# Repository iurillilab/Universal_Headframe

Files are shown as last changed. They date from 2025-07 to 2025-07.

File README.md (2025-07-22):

IIT-Rovereto Modular Mouse Headframe Clamp  
===========================================  

> A lightweight, Allen-compatible head-fixation system for imaging, electrophysiology and FUS studies  
> *Design series NT_NCS002* – by **Fabio Ricci** & **Giuliano Iurilli**, IIT Center for Neuroscience and Cognitive Systems, Rovereto (Italy), 2024 – 25

---
323248352-13070441-1c27-4a35-8a60-9cb97c2f6576

## 1. Purpose  

Sharing mice and rigs across projects is much simpler when the mechanical interface is identical everywhere.  
This repository provides the CAD, manufacturing drawings and assembly notes for the headframe clamp we use in the Gozzi, Iurilli and Rossi labs. The clamp:

* registers a titanium headplate (≈ 1.4 g) with micron-level repeatability;  
* mates directly to standard Thorlabs metric pillars or to a stereotaxic frame;  
* keeps the visual field unobstructed (design lineage: Allen Brain Observatory headframe);  
* survives running-mouse loads – static and dynamic deflection were bench-tested as ([P.A. Groblewski et al](https://www.sciencedirect.com/science/article/pii/S0165027020303459));  
* offers a kinematic reference that lets us reuse Allen Institute probe-positioning jigs and transparent hemisphere coordinate frames.

---

## 2. Repository layout  

```
/
├─ cad/               STEP
├─ drawings/          Dimensioned PDFs (NT_NCS002_001_P_001-004)
├─ bom/               CSV bill-of-materials
├─ headplate_variants/ Headplates STEP files
├─ accessories/       Accessories STEP files
└─ images/            Renders
```

---

## 3. Bill of Materials (BoM)  

| Item | Part No. | Qty | Material | Note |
|---|---|-----|---|---|
| 1 | **Stereotaxic mount** NT_NCS002_001_P_001 | 1 | SS 304 | Mates to KOPF/ASI frames |
| 2 | **Top headplate clamp** NT_NCS002_001_P_002 | 1 | SS 304 | Quick-release half-bridge |
| 3 | **Bottom headplate clamp** NT_NCS002_001_P_003 | 1 | SS 304 | Matches Allen bevel | 
| 4 | **Thorlabs pillar adapter** NT_NCS002_001_P_004 | 1 | SS 304 | Ø6 mm → Ø12.5 mm | 
| 5 | ISO 4026 M3×5 grub-screw | 2 | - | locking pins |
| 6 | ISO 4026 M3×8 grub-screw | 1 | - | axial stop |
| 7 | ISO 4762 M3 cap-screws (various 5–20 mm) | 6 | - | assembly |  

---

## 4. Fabrication guidelines  

* **CNC milling**: 3-axis is sufficient; minimum cutter Ø 1.6 mm.  
* **Tolerance**: unless stated,Dimensional Tolerance class -H Geometric Tolerance class -f, General tolerancesUNI EN 22768-1 / 22768-2 UNI ISO 8015
* **Surface finish**: Ra ≤ 1.6 µm on all mating faces; tumble-debur & passivate.  
* **Headplate**: Ti-TC4, 1.6 mm thick. The models in `/headplate_variants/` may be water-jet cut and bent or 3D printed by external manufacturer.  

---

## 5. Assembly & alignment workflow  

1. **Pre-load the clamp** – insert the M3 grub screws from the rear until flush.  
2. **Square to bregma** – fix the stereotaxic mount on the arm; use the printed bregma pointer to zero X/Y/Z.  
3. **Attach headplate to mouse** – follow your usual surgical SOP.  
4. **Clamp in** – slide the headplate under the bevel, tighten the single cap screw.  

---

## 6. Compatibility matrix  

| Instrument | Status | Notes |
|---|---|---|
| Wide-field mesoscope | ✅ | 200 mm working distance clears clamp |
| 2-photon 10× (Nikon A1R MP) | ✅ | headplate cone variant NT_NCS002_HP-C |
| Neuropixels v1.0/v2.0 | ✅ | uses Allen transparent coordinate frame |
| Functional -Ultrasound (FUS) | 🔄 | compatible cone in prototype (M. Urosevic) |

---

## 7. License  

All hardware documentation is released under **CERN-OHL-P v2**.  
You may manufacture and modify freely; derivatives must retain the same license and attribution.

---

## 8. Acknowledgements  

* Allen Institute open-hardware programme – for the original dual-hemisphere clamp design and coordinate frame  ([Toolkit - brain-map.org](https://portal.brain-map.org/explore/toolkit/hardware?utm_source=chatgpt.com)).  
* Iurilli laboratories for beta-testing across imaging and electrophysiology

---

*Maintainer*: **Fabio Ricci** – `<fabio.ricci@iit.it>`

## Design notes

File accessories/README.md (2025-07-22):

# Universal\_Headframe ─ Accessories Library 
Welcome!  This repository collects every **Accessories** we currently use or test at IIT Rovereto.  Each model comes as a STEP file (`.step`) ready for CAM / 3‑axis milling, direct metal‑AM printing, or SLA 3D printin, plus a PNG preview so you can eyeball the geometry before downloading CAD.

> **TL;DR**  • All files are **metric** (ISO M‑series screws, millimetres).

---

## How this README is organised

| Section | What you’ll find |
| --- | --- |
| [Quick chooser](#quick-chooser-table) | one‑line guide to pick the right plate |
| [Fabrication notes](#fabrication-notes) | tips for CNC vs SLM printing |

---

## Quick chooser table

| File name | Preview | Mass\* | Aperture Ø | Typical use‑case |
| --- | --- | --- | --- | --- |
| `0160-073-01_FR.step` || xx g | x mm | **Allen institute lineage** 	Cone for 2P|
| `Stamp_tool_SH_FR.step`|| xx  g | x mm | **Allen institute lineage** 	[SHIELD]( https://cad.onshape.com/publications/a9da3d5bea6057b1de9dcbe4/w/e8fb183696b8dd84a43603fb/e/8e9294519ca4564a8390c596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 ) stamp tool for creating impression of implant (0251-160-01) in putty during coating process|
| `DHC Stamp Tool_Stamp_tool_DH_FR.step`|| xx g | x mm |**Allen institute lineage**	[SHIELD]( https://cad.onshape.com/publications/a9da3d5bea6057b1de9dcbe4/w/e8fb183696b8dd84a43603fb/e/8e9294519ca4564a8390c596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 ) Dual Hemisphere Implant stamp tool for creating impression of implant (0274-100-22) in putty during coating process |
| `AH_USSEnterprise_cone_FR.step`|| xx g | x mm | **Skull‑contoured** cone for WFI compatible with AH_USSEnterprise_FR Headplate |
| `AH_USSEnterprise_cover.step`|| xx g | x mm |**Skull‑contoured** screwable open cover for the cone 			 |
| `Luigi_cone.step`|| xx g | x mm |Luigi Headplate variant cone for Ephys|
<sub>\*Mass values are printed Ti‑TC4 as measured on a 0.1 mg balance</sub>

---

## Fabrication notes

* **3‑D printing (SLM)** – upload to JLC3DP or similar; choose **Ti‑TC4** and "high precision" option if offered.
* **CNC milling** – water‑jet or laser‑cut 1.6 mm Ti sheet, then finish on 3‑axis mill;
* **3-D printing  (SLA)** - Used a Form 2 for parts that does not endure loads.

---

### Contributing

Pull requests welcome—open an issue if you have a new variant or measurement data to share.

### License

CERN-OHL-P-2.0 license.

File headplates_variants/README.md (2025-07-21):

# Universal\_Headframe ─ Variant Library 
Welcome!  This repository collects every **head‑plate variant** we currently use or test at IIT Rovereto.  Each model comes as a STEP file (`.step`) ready for CAM / 3‑axis milling, direct metal‑AM printing, or SLA 3D printin, plus a PNG preview so you can eyeball the geometry before downloading CAD.

> **TL;DR**  • All files are **metric** (ISO M‑series screws, millimetres). • Default material is **Ti‑TC4** (works in SLM or CNC), some of them can be made in plastic.

---

## How this README is organised

| Section | What you’ll find |
| --- | --- |
| [Quick chooser](#quick-chooser-table) | one‑line guide to pick the right plate |
| [Fabrication notes](#fabrication-notes) | tips for CNC vs SLM printing |

---

## Quick chooser table

| File name | Preview | Mass\* | Aperture Ø | Typical use‑case |
| --- | --- | --- | --- | --- |
| `0160-075-00_FR.step` | | xx g | x mm | **Allen institute lineage** 	titanium headframe utilized with the [SHIELD]( https://cad.onshape.com/publications/a9da3d5bea6057b1de9dcbe4/w/e8fb183696b8dd84a43603fb/e/8e9294519ca4564a8390c596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 ) implant for dual hemisphere electrophysiological recordings|
| `0251-900-04_FR.step` || xx  g | x mm | **Allen institute lineage**  Headframe-shank mounted stylus for setting stereotax clamp location with respect to Bregma|
| `0251-910-00_FR.step` || xx g | x mm |**Allen institute lineage**Headframe-shank mounted Whole Hemisphere Implant Tracer |
| `AH_USSEnterprise_FR.step` || xx g | x mm | **Skull‑contoured** geometry—full compatibility, acute imaging, [SHIELD]( https://cad.onshape.com/publications/a9da3d5bea6057b1de9dcbe4/w/e8fb183696b8dd84a43603fb/e/8e9294519ca4564a8390c596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 ) implant for dual hemisphere electrophysiological recordings |
| `DHC Tracer_FR.step` || xx g | x mm | Headframe-shank mounted Dual Hemisphere Implant Tracer 			 |
| `Eppendorf_FR.step` || xx g | x mm | Plate with keyed seat for Eppendorf to insert NP2 shanks |
| `Luigi_Headplate_V1_FR.step` || xx g | x mm | Luigi petrucco variant Ephys|
| `0160-055-00_X01_FR.step` || xx g | x mm | variant. |
| `0160-073-00_A_FR.step` || xx g | x mm | **Allen institute lineage** 	titanium headframe utilized with the [SHIELD]( https://cad.onshape.com/publications/a9da3d5bea6057b1de9dcbe4/w/e8fb183696b8dd84a43603fb/e/8e9294519ca4564a8390c596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 ) implant for whole hemisphere electrophysiological recordings - Version 2 - Ring style.|

<sub>\*Mass values are printed Ti‑TC4 as measured on a 0.1 mg balance</sub>

---

## Fabrication notes

* **3‑D printing (SLM)** – upload to JLC3DP or similar; choose **Ti‑TC4** and "high precision" option if offered.
* **CNC milling** – water‑jet or laser‑cut 1.6 mm Ti sheet, then finish on 3‑axis mill;
* **3-D printing  (SLA)** - Used a Form 2 for parts that does not endure loads.

---

### Contributing

Pull requests welcome—open an issue if you have a new variant or measurement data to share.

### License

CERN-OHL-P-2.0 license.

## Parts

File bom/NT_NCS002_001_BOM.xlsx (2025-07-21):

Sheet: components request
# | Cod. | Rev. | Q.ty | Mfg. Technology | Material | Notes | Optional column 1 | Optional column 2
1 | NT_BMP005_001_P_001 |  | 4 | CNC / Machine Tools
2 | NT_BMP005_001_P_002 |  | 4 | CNC / Machine Tools
3 | NT_BMP005_001_P_003 |  | 4 | CNC / Machine Tools
4 | NT_BMP005_003_P_004 |  | 4 | CNC / Machine Tools

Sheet: processes
Mgf. Technologies
Additive Mfg. (any)
SLS (ProX6100)
Polyjet (Connex500)
SLA (XFAB3500SD)
FFF (Fortus400)
CNC / Machine Tools
Waterjet
Inserts/Helicoils
Mech. Assembly
Reworked Comp.
Other

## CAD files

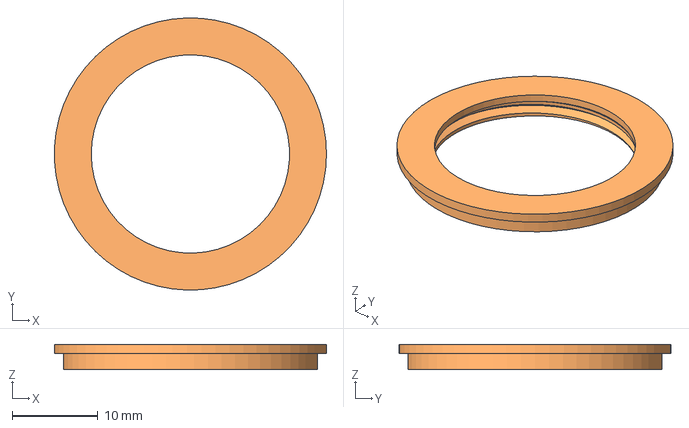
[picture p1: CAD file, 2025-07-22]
accessories/AH_USSEnterprise_cover.step
31.7 x 31.7 x 2.94 mm

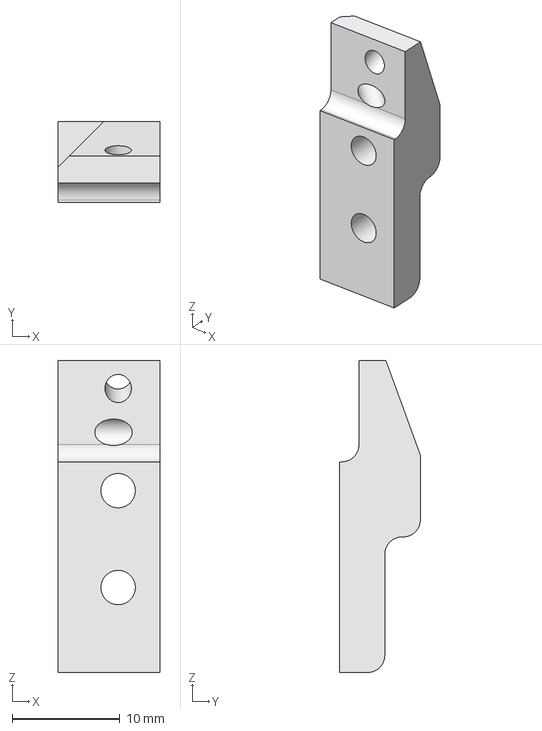
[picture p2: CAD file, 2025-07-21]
cad/NT_NCS002_001_P_002.stp
9.50 x 7.50 x 29.0 mm

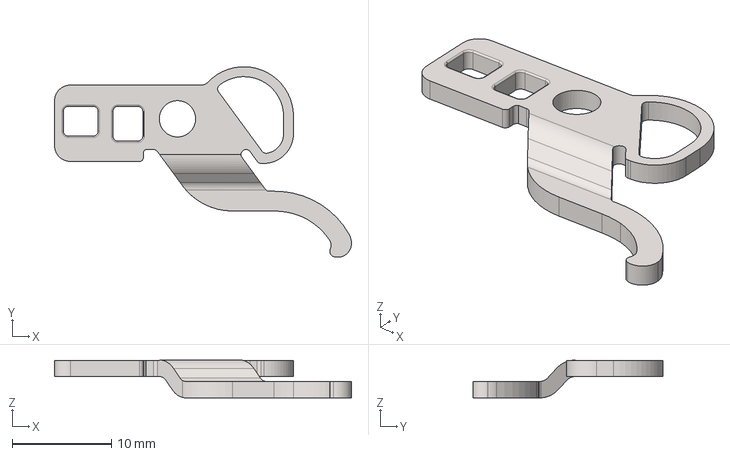
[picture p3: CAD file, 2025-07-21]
headplates_variants/Luigi_Headplate_V1_FR.step
29.9 x 19.2 x 3.83 mm

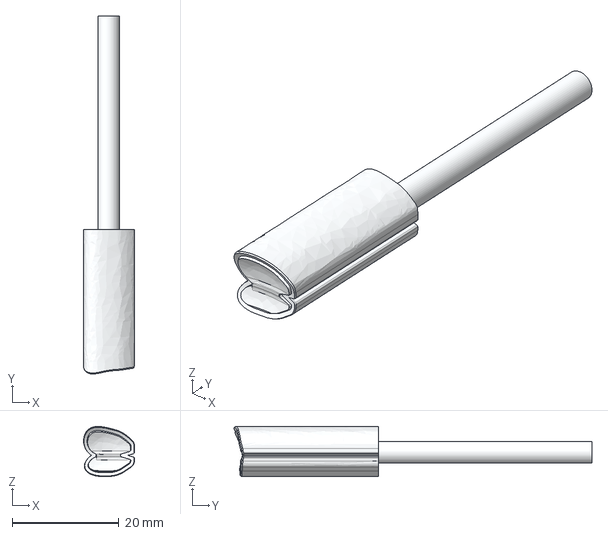
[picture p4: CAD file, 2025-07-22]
accessories/DHC Stamp Tool_Stamp_tool_DH_FR v1.step
9.54 x 67.1 x 9.39 mm

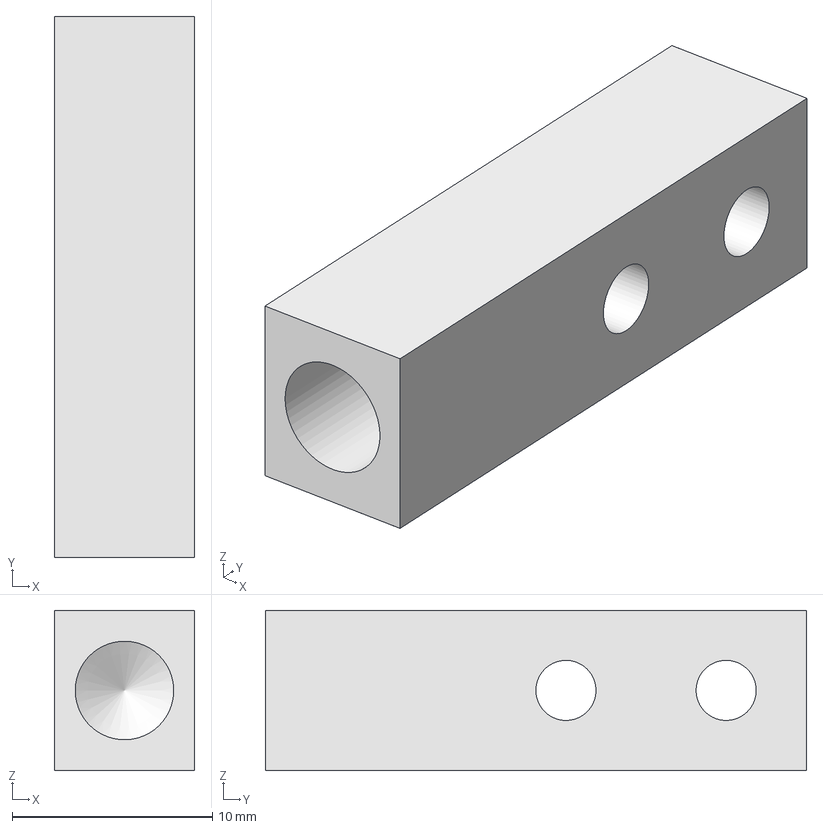
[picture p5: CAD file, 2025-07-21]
cad/NT_NCS002_001_P_004.stp
7.00 x 27.0 x 8.00 mm

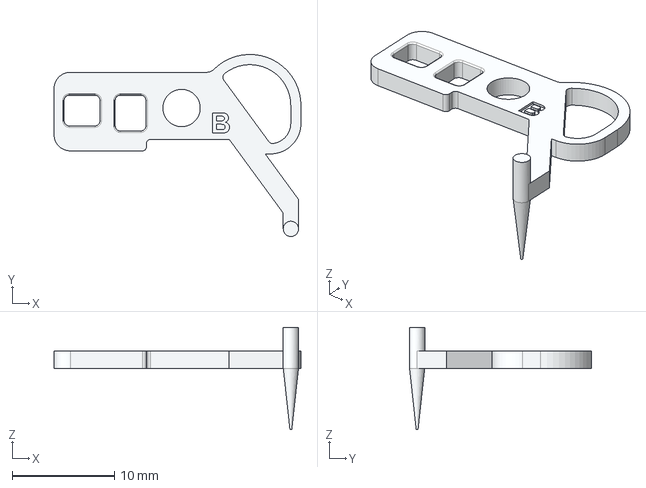
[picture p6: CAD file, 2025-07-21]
headplates_variants/0251-900-04_FR.step
24.2 x 17.8 x 10.0 mm

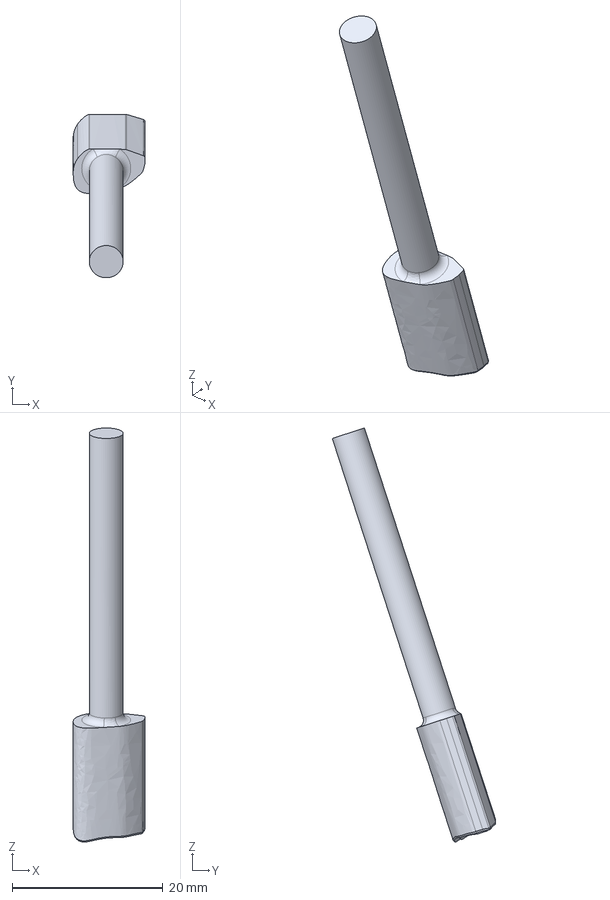
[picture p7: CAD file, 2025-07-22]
accessories/Stamp_tool_SH_FR v1.step
9.51 x 21.7 x 54.9 mm

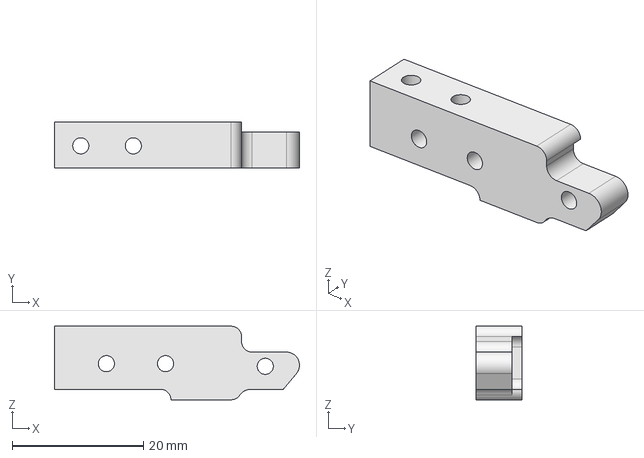
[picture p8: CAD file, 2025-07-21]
cad/NT_NCS002_001_P_003.stp
37.3 x 7.02 x 11.2 mm

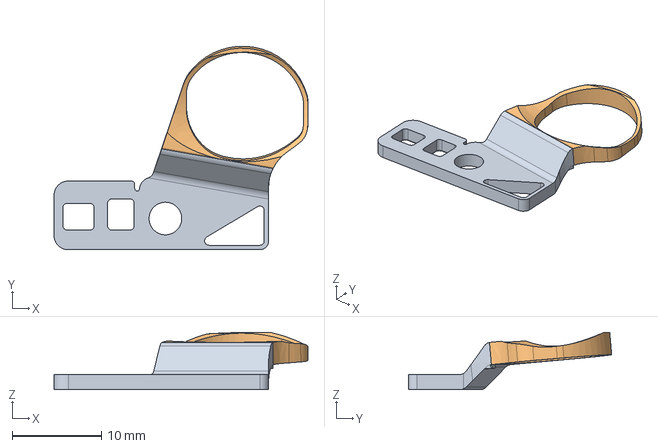
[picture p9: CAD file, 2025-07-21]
headplates_variants/0160-075-00_FR.step
28.5 x 22.8 x 6.42 mm

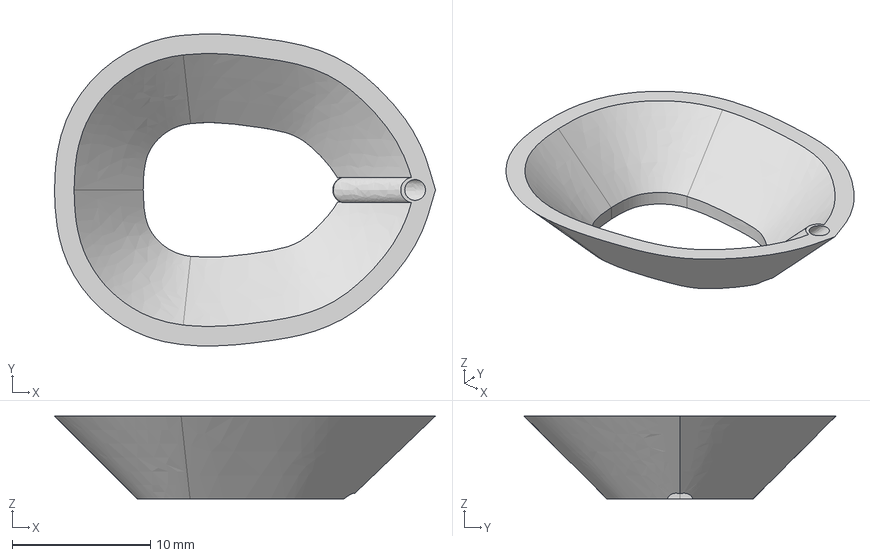
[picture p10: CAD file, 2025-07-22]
accessories/Luigi_cone.step
27.5 x 22.6 x 6.00 mm

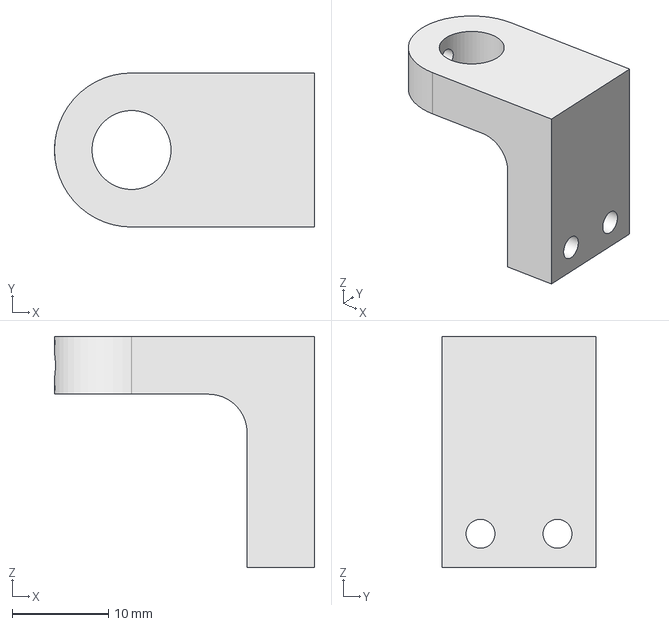
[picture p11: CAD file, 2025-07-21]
cad/NT_NCS002_001_P_001.stp
27.0 x 16.0 x 24.0 mm

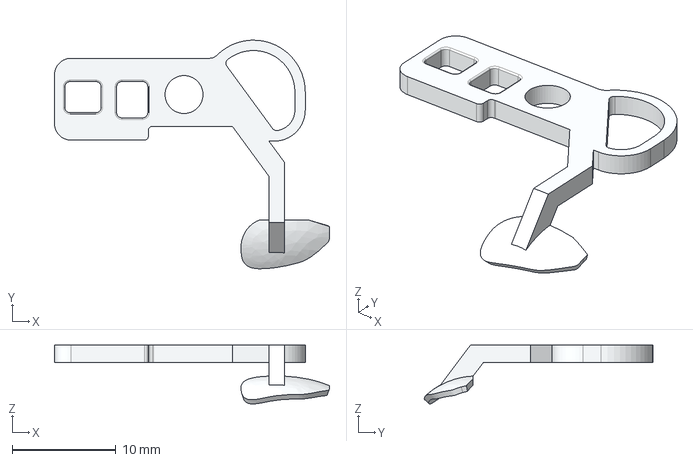
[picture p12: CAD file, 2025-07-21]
headplates_variants/0251-910-00_FR.step
26.5 x 22.1 x 5.69 mm

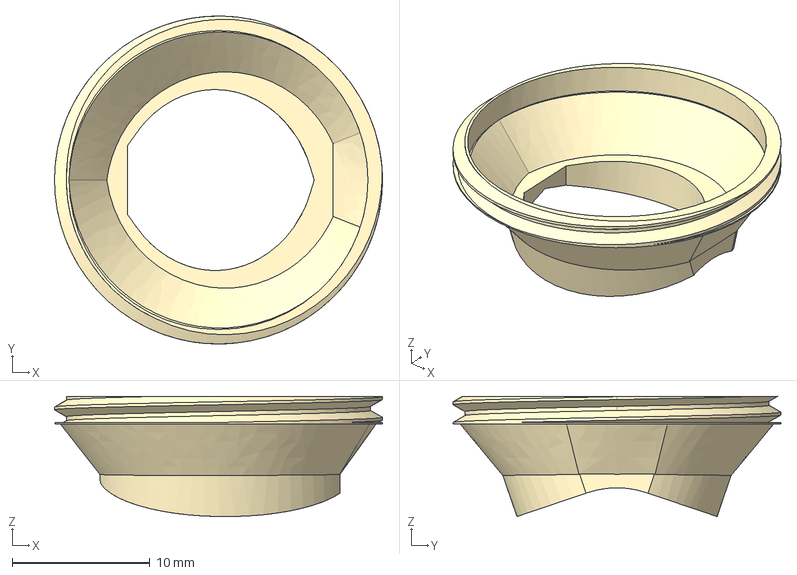
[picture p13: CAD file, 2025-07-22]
accessories/AH_USSEnterprise_cone_FR.step
23.9 x 23.8 x 8.74 mm

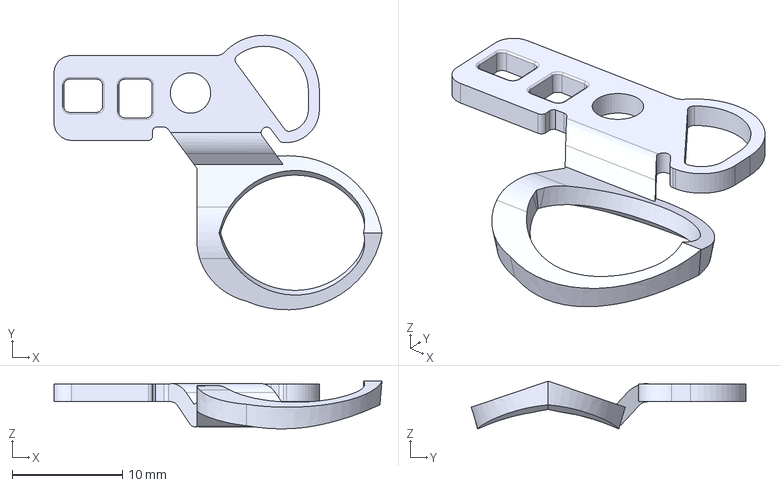
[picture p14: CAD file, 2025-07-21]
headplates_variants/AH_USSEnterprise_FR.step
29.8 x 24.9 x 4.33 mm

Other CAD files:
accessories/0160-073-01_FR.step
headplates_variants/Eppendorf_FR.step
headplates_variants/DHC Tracer_FR.step
headplates_variants/0160-073-00_A_FR.step
headplates_variants/0160-055-00_X01_FR.step

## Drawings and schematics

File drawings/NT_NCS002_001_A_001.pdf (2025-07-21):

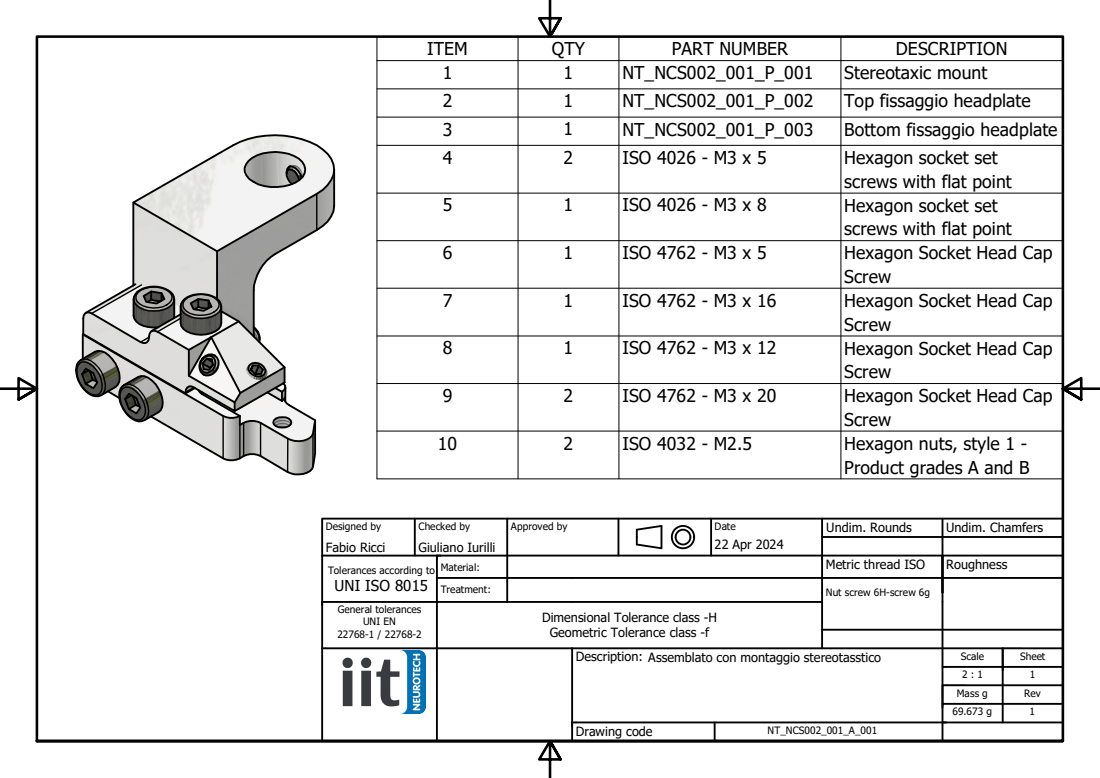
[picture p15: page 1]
Fabio Ricci; Giuliano Iurilli; 22 Apr 2024; Designed by; Checked by; Approved by; Date; Undim. Rounds; Undim. Chamfers

ITEM | QTY | PART NUMBER | DESCRIPTION
1 | 1 | NT_NCS002_001_P_001 | Stereotaxic mount
2 | 1 | NT_NCS002_001_P_002 | Top fissaggio headplate
3 | 1 | NT_NCS002_001_P_003 | Bottom fissaggio headplate
4 | 2 | ISO 4026 - M3 x 5 | Hexagon socket set screws with flat point

5 | 1 | ISO 4026 - M3 x 8 | Hexagon socket set screws with flat point

6 | 1 | ISO 4762 - M3 x 5 | Hexagon Socket Head Cap Screw

7 | 1 | ISO 4762 - M3 x 16 | Hexagon Socket Head Cap Screw

8 | 1 | ISO 4762 - M3 x 12 | Hexagon Socket Head Cap Screw

9 | 2 | ISO 4762 - M3 x 20 | Hexagon Socket Head Cap Screw

10 | 2 | ISO 4032 - M2.5 | Hexagon nuts, style 1 -Product grades A and B

Tolerances according to UNI ISO 8015 | Material: | Metric thread ISO | Roughness

Treatment: | Nut screw 6H-screw 6g

General tolerances UNI EN 22768-1 / 22768-2 | Dimensional Tolerance class -H Geometric Tolerance class -f

Description: Assemblato con montaggio stereotasstico | Scale | Sheet

Mass g | Rev
69.673 g | 1

Drawing code | NT_NCS002_001_A_001

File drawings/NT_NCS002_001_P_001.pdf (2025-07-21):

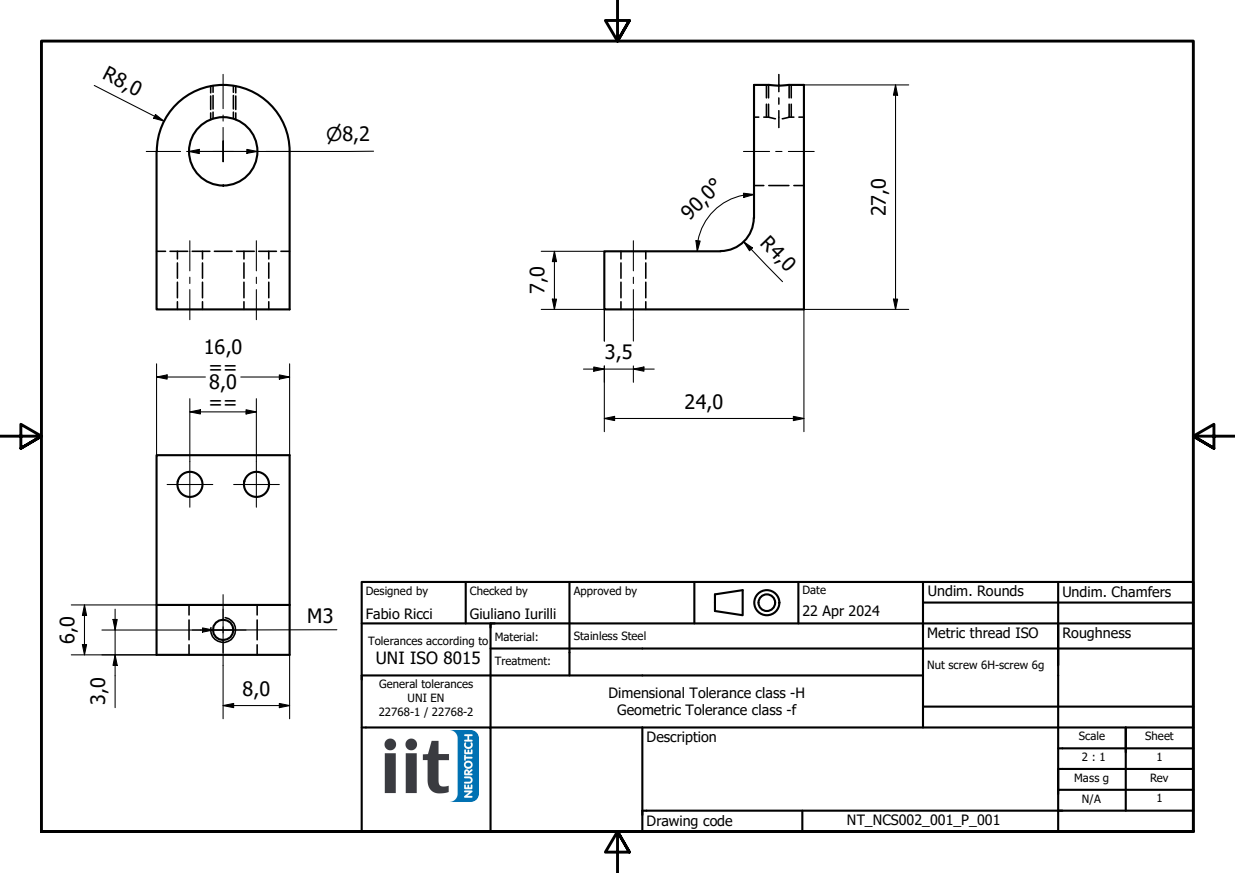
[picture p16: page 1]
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

Tolerances according to UNI ISO 8015 | Material: | Stainless Steel | Metric thread ISO | Roughness

Treatment: | | Nut screw 6H-screw 6g

General tolerances UNI EN 22768-1 / 22768-2 | Dimensional Tolerance class -H Geometric Tolerance class -f

Description | Scale | Sheet

Mass g | Rev
N/A | 1

Drawing code | NT_NCS002_001_P_001

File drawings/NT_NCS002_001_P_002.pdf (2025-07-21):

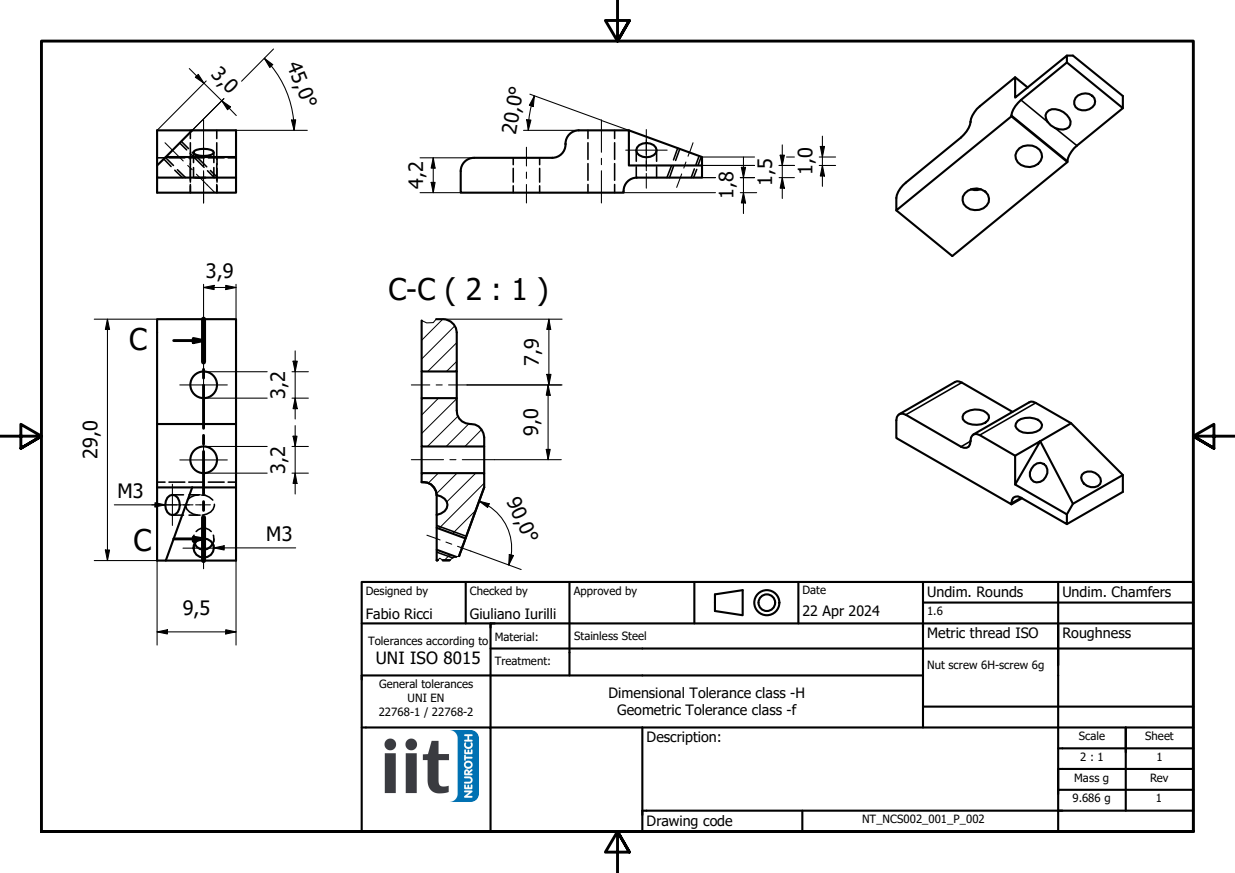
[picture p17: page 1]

Designed by Fabio Ricci | Checked by Giuliano Iurilli | Approved by | | Date 22 Apr 2024 | Undim. Rounds | Undim. Chamfers

Tolerances according to UNI ISO 8015 | Material: | Stainless Steel | Metric thread ISO | Roughness

Treatment: | | Nut screw 6H-screw 6g

General tolerances UNI EN 22768-1 / 22768-2 | Dimensional Tolerance class -H Geometric Tolerance class -f

Description: | Scale | Sheet

Mass g | Rev
9.686 g | 1

Drawing code | NT_NCS002_001_P_002
